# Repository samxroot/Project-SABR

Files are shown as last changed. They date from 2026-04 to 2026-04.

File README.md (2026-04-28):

# SABR - Self-Balancing Robot (Inverted Pendulum)

[](https://youtu.be/h8H8bgWLwpI)

[sabr-demo]: https://img.youtube.com/vi/h8H8bgWLwpI/maxresdefault.jpg

### A LIGIENCE Project

**SABR** is a self-balancing robot built from scratch using control theory, embedded systems, and iterative engineering. This project explores the inverted pendulum problem in a real-world system using sensor fusion and PID control.

## Quick Start

### 1. Hardware

- 3D print parts from `hardware/cad/stl/`
- Order PCB from `hardware/pcb/gerbers/`
- Follow wiring diagram in `docs/wiring.md`

### 2. Firmware

- Open `firmware/sabr.ino`
- Upload to ESP32 using Arduino IDE or PlatformIO

### 3. Run

- Power the robot upright
- Tune PID values if needed (`config.h` or inline constants)

## Overview

**SABR** balances using:

- IMU-based angle measurement (MPU6050)
- Sensor fusion (Kalman / Complementary filter)
- PID control loop (~200Hz)
- Real-time motor correction

## Features

- [x] Custom mechanical design (CAD + 3D printed)
- [x] Custom PCB (KiCad)
- [x] Sensor fusion (Kalman / Complementary filter)
- [x] 200 Hz PID control loop
- [x] Real-time motor correction
- [x] Multiple motor configurations tested

## Project Structure

```
hardware/
  ├── cad/            # STEP + STL files
  ├── pcb/            # Gerbers + schematic
  └── electronics/    # Fritzing

firmware/
  └── sabr.ino

docs/
  ├── build-guide.md
  ├── motor-sizing.md
  └── development.md

media/
```

## Components

| Component | Details |
|---|---|
| **Microcontroller** | ESP32 Dev Module |
| **IMU** | MPU6050 (6-axis accelerometer + gyroscope) |
| **Motors** | NEMA 17 Stepper Motors |
| **Motor Drivers** | TMC2208 |
| **Power** | LiPo Battery + Buck Converter |
| **Frame** | Custom PCB + 3D printed chassis |

Full component list: [`hardware/BOM.md`](hardware/BOM.md)

## How It Works

```
IMU Data → Sensor Fusion → PID Controller → Motor Output → Balance
```

- Control loop runs at ~200Hz
- D-term uses gyroscope data directly for stability
- Kalman filter tuned with high gyro weighting (>95%)

## Documentation

| Resource | Link |
|---|---|
| Build Guide | [`docs/build-guide.md`](docs/build-guide.md) |
| Motor Sizing | [`docs/motor-sizing.md`](docs/motor-sizing.md) |
| Development Process | [`docs/development.md`](docs/development.md) |

### Additional Learning Resources

**Sensor Fusion & Filtering:**
- [Complementary & Kalman Filters Overview](https://youtu.be/7HVPjkWOrLE?si=l8aKTfFblnUTjnXL)
- [Complementary Filter Deep Dive](https://youtu.be/hQUkiC5o0JI?si=4qGIxBiCNVThZBNw)
- [Kalman Filter Implementation](https://youtu.be/RZd6XDx5VXo?si=hTg3l8ioiw1hPVCZ)

**IMU Processing:**
- [Accelerometer Roll & Pitch Explanation](https://mwrona.com/posts/accel-roll-pitch/)

## Visuals

### Circuit Diagram
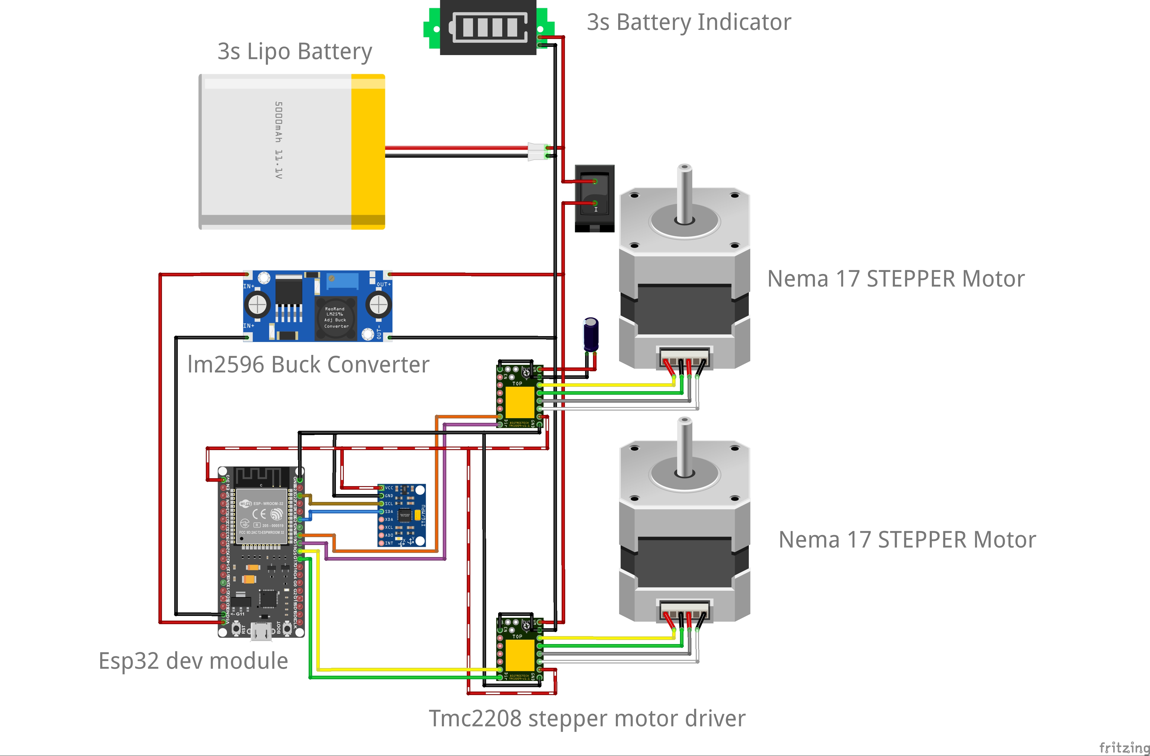
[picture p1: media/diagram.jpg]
Circuit Diagram


### Schematics
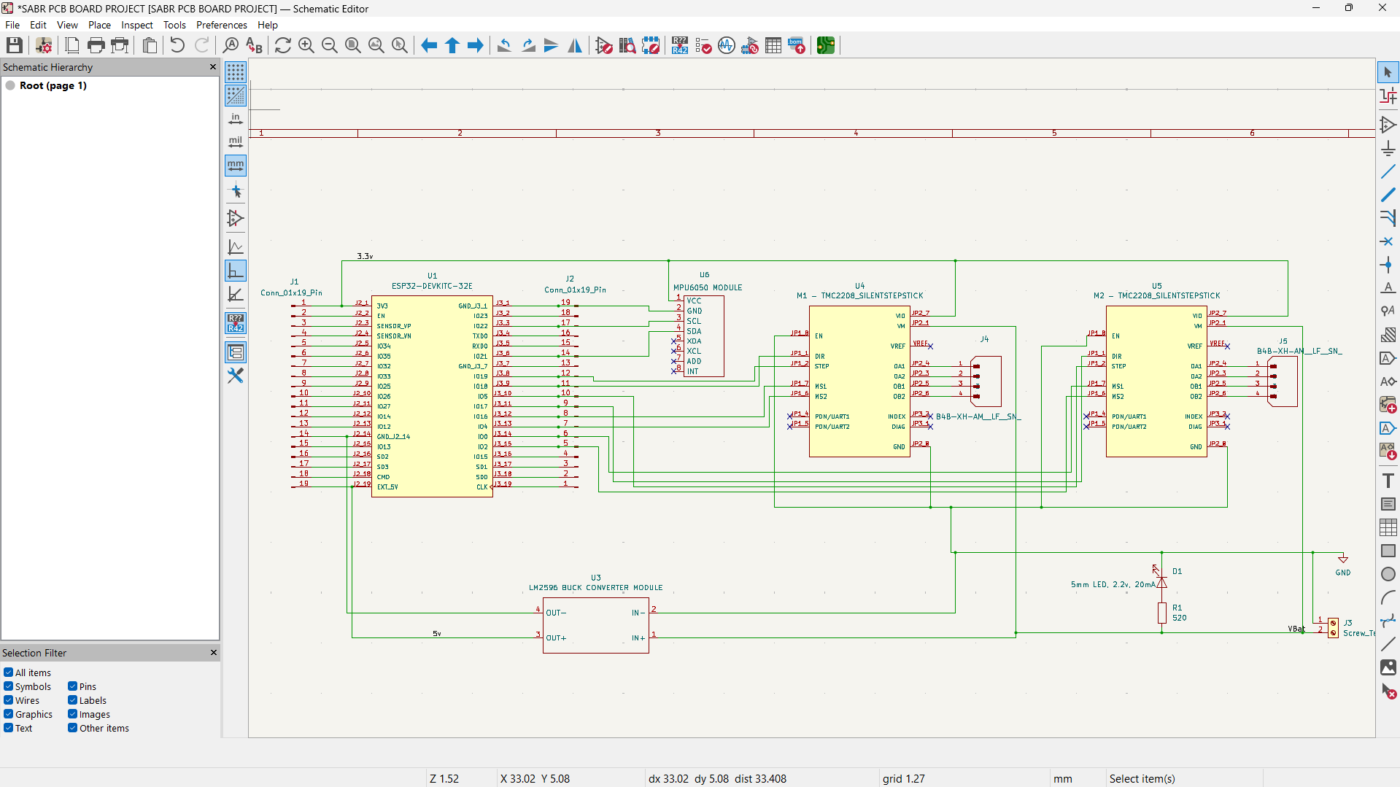
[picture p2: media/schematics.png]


### PCB Layout
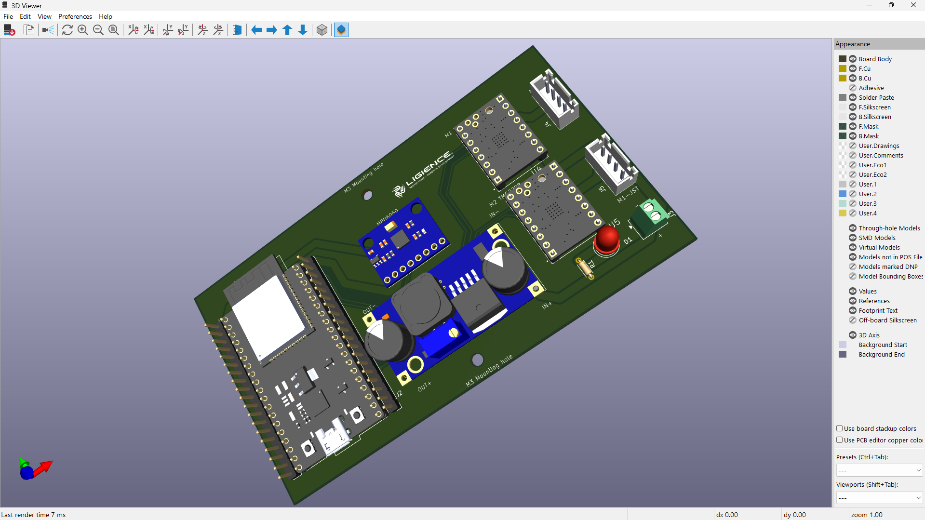
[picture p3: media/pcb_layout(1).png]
PCB Layout

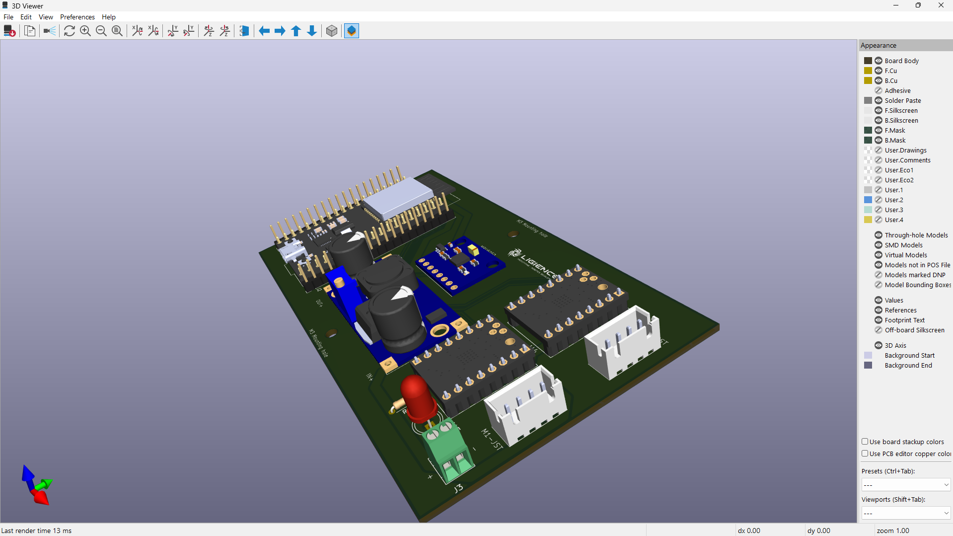
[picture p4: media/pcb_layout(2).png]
PCB Layout


### 3D Model
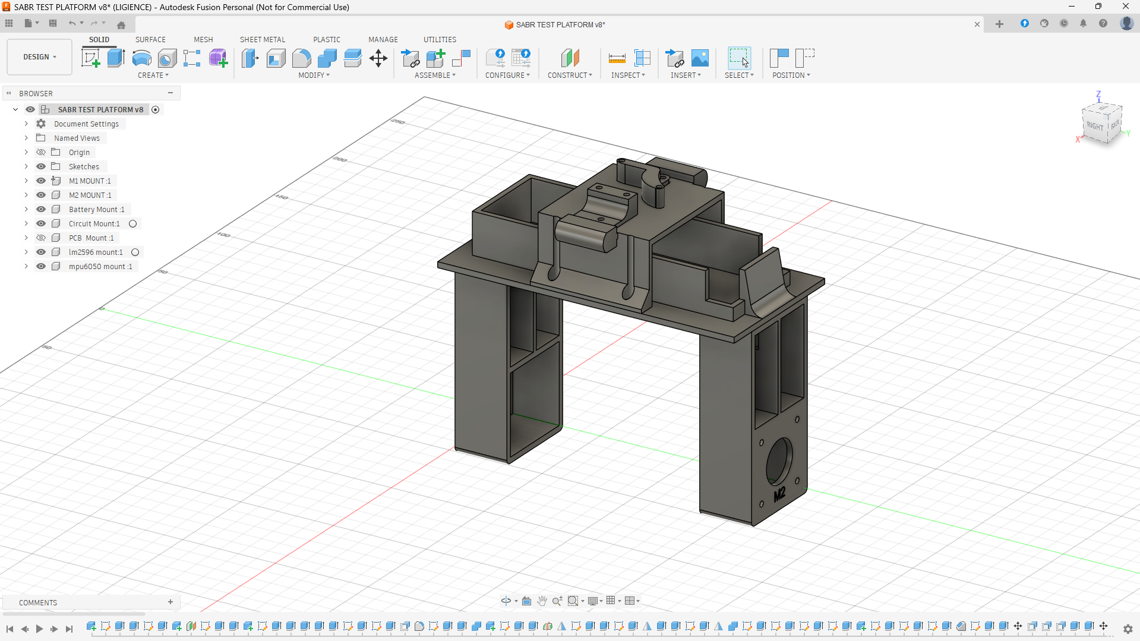
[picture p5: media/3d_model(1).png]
3D Model

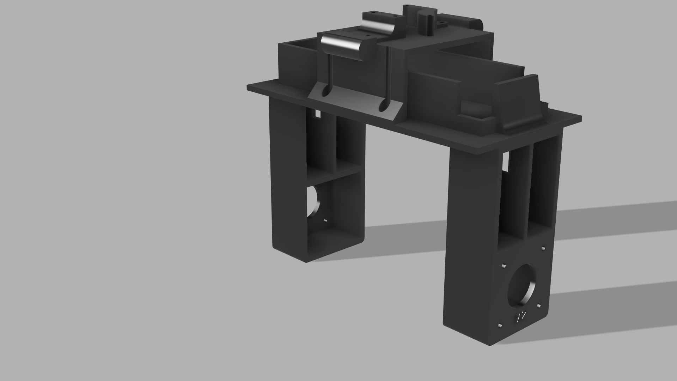
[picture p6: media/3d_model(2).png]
3D Model

<div align="center">
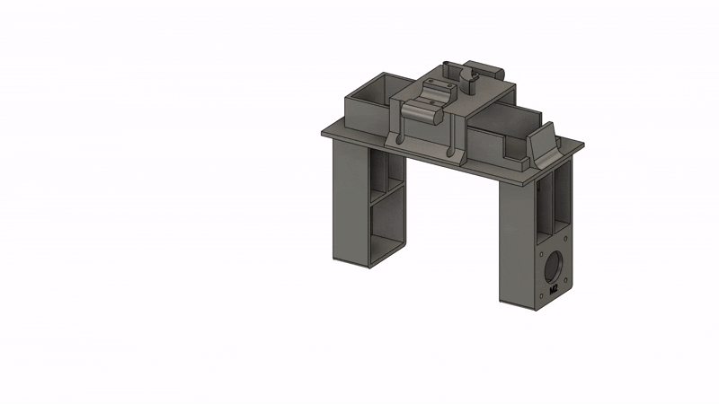
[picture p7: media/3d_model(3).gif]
3D Model Animation
  
</div>

## Known Issues & Future Work

- [ ] Add position/velocity control (reduce drift)
- [ ] Improve wheel grip (silicone tyres)
- [ ] Add power switch to PCB
- [ ] Add wheel encoders for odometry
- [ ] Explore BLDC motors with FOC control

## Credits

- Inspiration: [Aaed Musa's Impulse Robot](https://youtu.be/WIU8gnqQJJM)
- PCB Manufacturing: [PCBWay](https://www.pcbway.com)
- Control Theory References: See `/docs`

*Part of the LIGIENCE robotics series - building real robots from first principles.*

## License

[MIT License](LICENSE)

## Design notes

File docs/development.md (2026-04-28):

# Development Journey

## Phase 1 — Physics & Modelling

* Inverted pendulum system
* Derived equations of motion

## Phase 2 — Prototyping

* ESP32 + MPU6050
* Complementary & Kalman filters tested

## Phase 3 — Stepper V1

* Torque issues, overheating

## Phase 4 — Stepper V2

* Improved but unstable

## Phase 5 — Motor Experiments

* DC motors → dead zone issues
* Servos → too slow

## Phase 6 — Breakthrough

* Root issue: wheel friction
* Successful balancing on carpet
* Kalman tuning improved stability

## Phase 7 — Final Tuning

* PID tuning (Kp → Kd → Ki)
* Gyro-based D term
* Stable balancing achieved

## Key Lessons

* Hardware matters more than tuning
* Friction is critical
* Motor response speed is everything

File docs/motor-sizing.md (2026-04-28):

# Motor Sizing & Torque Calculation
Source: [CTMS - Inverted Pendulum Model](https://ctms.engin.umich.edu/CTMS/?example=InvertedPendulum&section=SystemModeling)

## Formula

`τ = m · g · L · sin(θ)`

## Variables

- **τ** - Torque (N·m)
- **m** - Mass of the robot (kg)
- **g** - Gravitational acceleration (9.81 m/s²)
- **L** - Distance from wheel axle to center of mass (m)
- **θ** - Tilt angle (degrees)

## Guidelines

- Use θ ≥ 30° as the minimum recovery angle.
- Multiply the calculated torque by a 1.5×–2× safety margin.
- Never select motors at the minimum torque specification.

## Key Insights

### Torque vs Inertia

- **Torque ∝ L** - Torque increases with the distance from the pivot.
- **Inertia ∝ L²** - Longer robots require more torque to counterbalance increased inertia.

### Dead Zones

DC motors often have a 0–40% PWM dead zone, where small PID corrections may fail to move the motor.

### Stepper Limitations

- Stepper motors can overheat due to high current draw at standstill.
- This can lead to thermal shutdown under continuous correction.

### Critical Rule

You cannot fix insufficient hardware with PID tuning. Ensure your motor provides enough torque and response speed.

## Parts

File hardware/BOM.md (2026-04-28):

## Components
* ESP32 Dev Module
* MPU6050 IMU
* NEMA 17 Stepper Motors (final version)
* TMC2208 Drivers
* LiPo Battery + Buck Converter
* Custom PCB + 3D printed frame

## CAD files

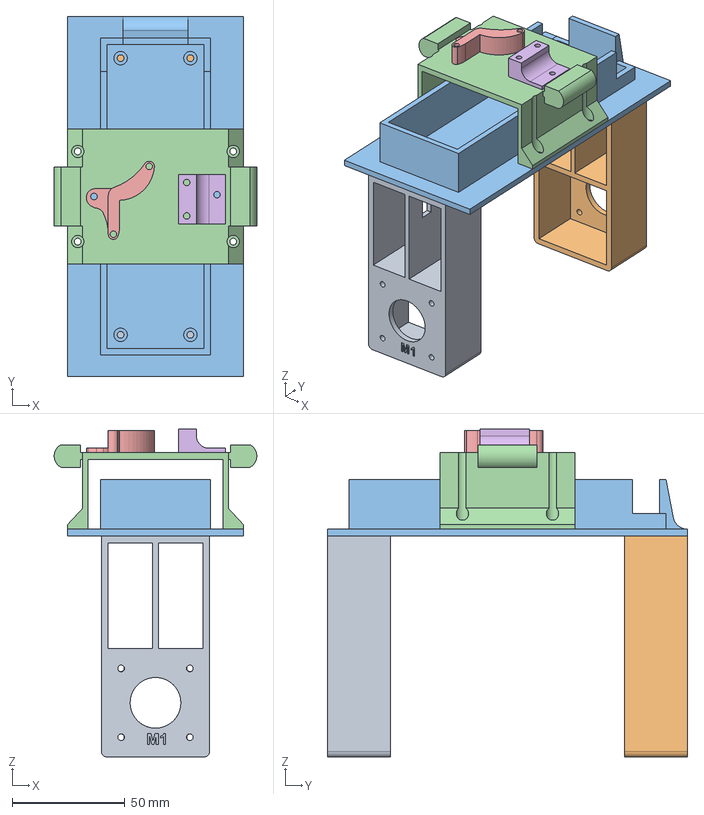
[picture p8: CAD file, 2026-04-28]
hardware/cad/step/test-platform.step
90.0 x 160.0 x 145.6 mm
M1 MOUNT
M2 MOUNT
Battery Mount
Circuit Mount
lm2596 mount
mpu6050 mount

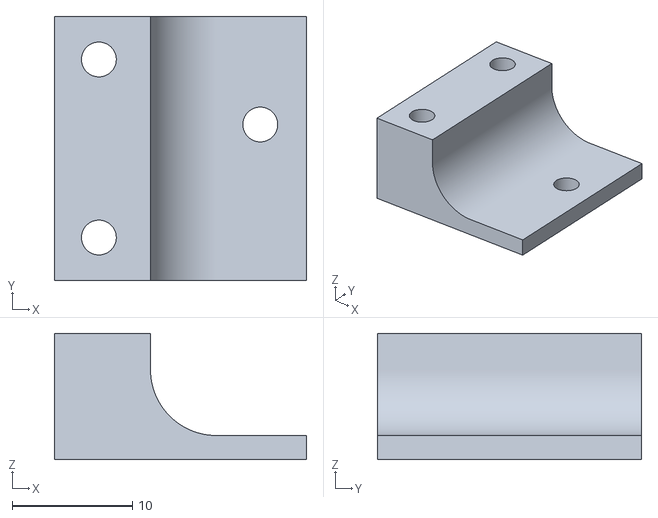
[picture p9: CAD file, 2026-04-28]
hardware/cad/stl/MPU6050 Mount.stl
21.0 x 22.0 x 10.5

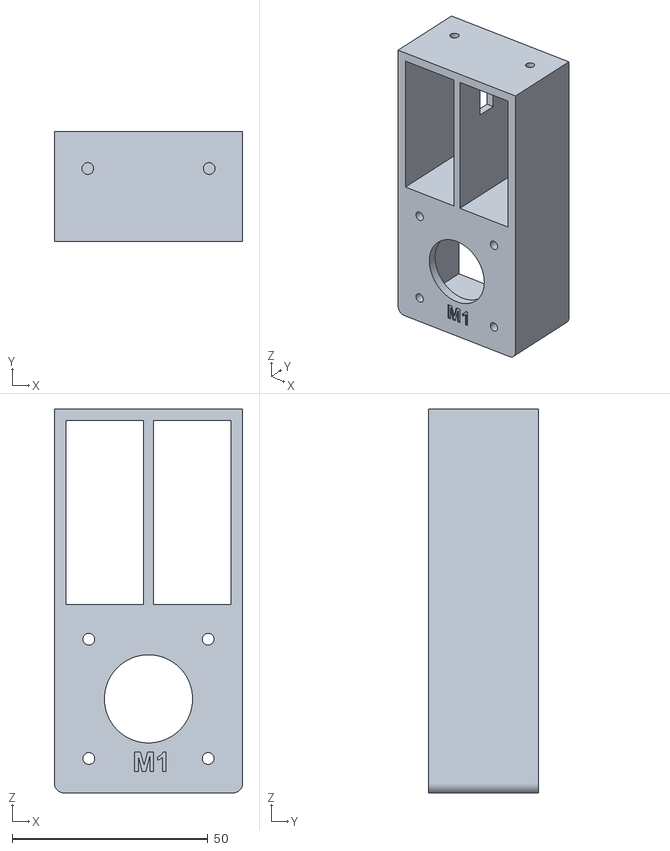
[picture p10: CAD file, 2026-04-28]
hardware/cad/stl/M1 Mount.stl
48.1 x 28.0 x 98.1

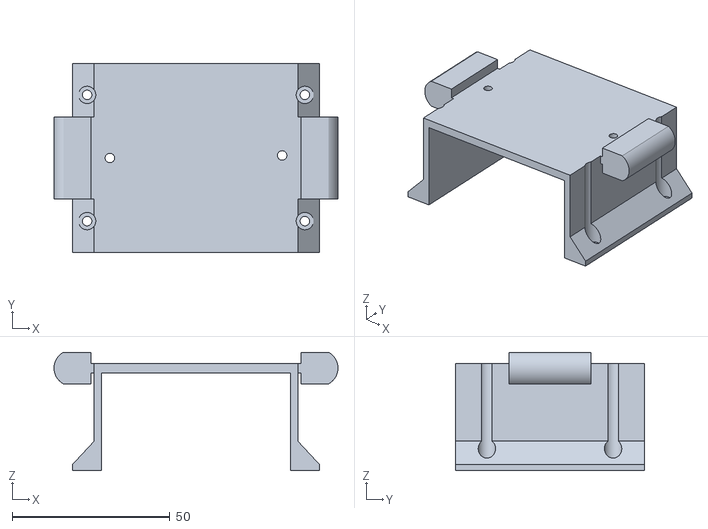
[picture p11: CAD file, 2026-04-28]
hardware/cad/stl/Circuit Mount.stl
90.0 x 60.0 x 37.5

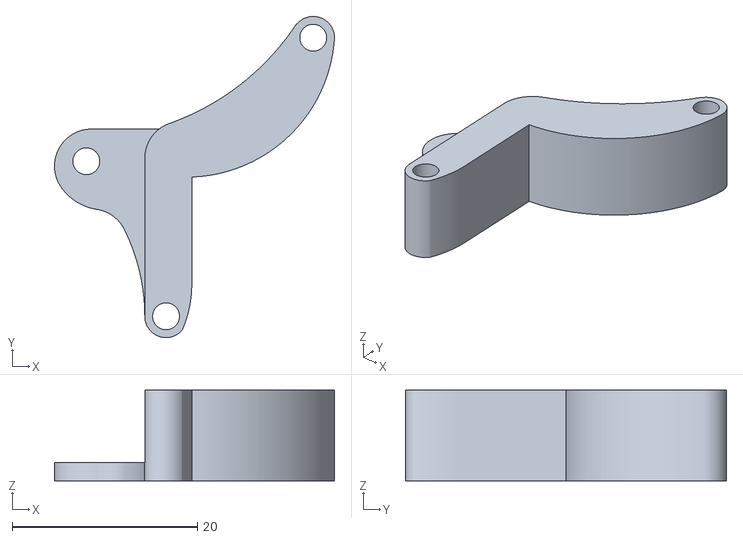
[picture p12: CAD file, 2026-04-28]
hardware/cad/stl/LM2596 Mount.stl
30.3 x 34.7 x 9.80

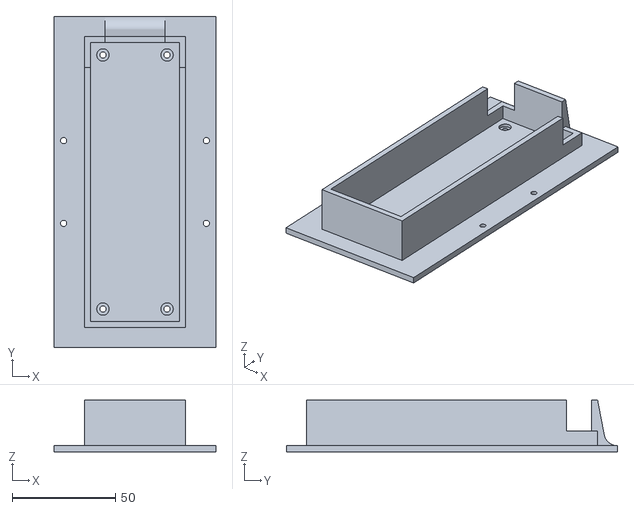
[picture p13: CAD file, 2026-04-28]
hardware/cad/stl/Battery Mount.stl
78.1 x 160.0 x 25.0

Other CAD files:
hardware/cad/stl/M2 Mount.stl

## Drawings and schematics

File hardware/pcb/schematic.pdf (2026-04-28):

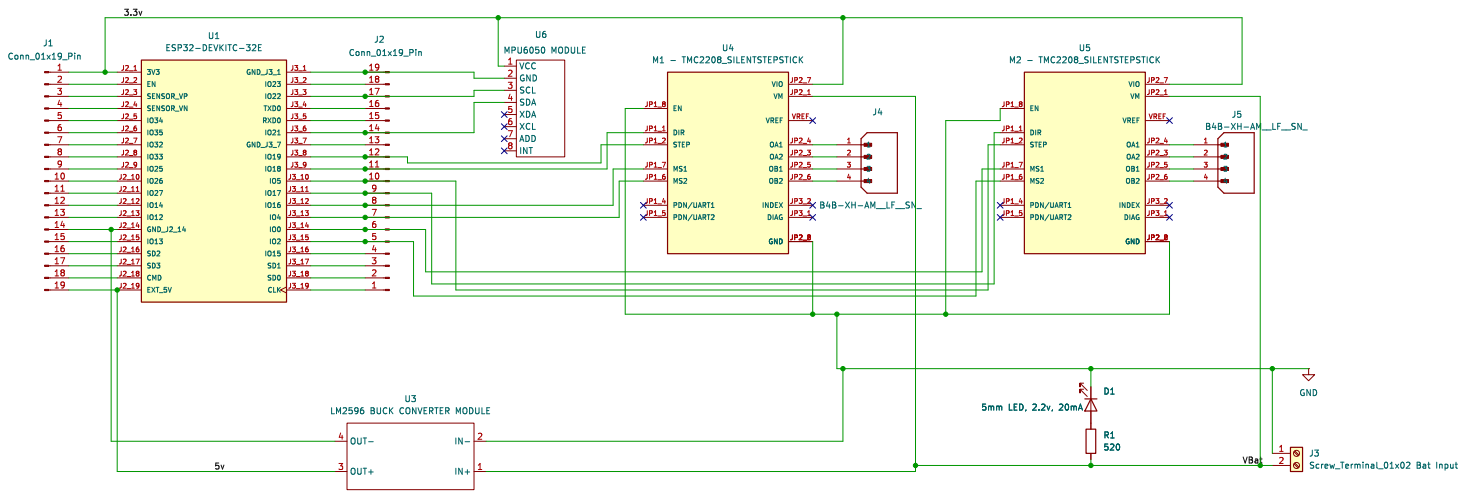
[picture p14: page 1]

Id: 1/1 Title: SABR PCB DESING

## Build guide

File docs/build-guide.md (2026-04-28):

# Build Guide (Overview)
Follow along: [A Self Balancing Robot Journey | Building SABR](https://youtu.be/h8H8bgWLwpI)

## 1. Print Parts

Use STL files in `hardware/cad/stl/`

## 2. Assemble Frame

* Mount motors
* Attach wheels
* Secure electronics

## 3. PCB

* Order from `hardware/pcb/gerbers/`
* Solder components

## 4. Wiring

Follow `docs/wiring.md`

## 5. Upload Firmware

Flash `firmware/sabr.ino` to ESP32

## 6. First Test

* Hold robot upright
* Power on
* Adjust PID if unstable

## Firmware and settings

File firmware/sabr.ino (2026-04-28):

// PLEASE UNDERSTAND I WRITE COMMENTS MY OWN WAY,
// BUT NONETHELESS THE BUILD VIDEO FOR THIS IS ON YOUTUBE @LIGIENCE
// Link: https://youtube.com/@LIGIENCE

#include <Wire.h>
#include <math.h> // Required for sqrt, atan2f, fabsf

// -------------------- IMU VARIABLES --------------------

float Gyro_Roll, Gyro_Pitch, Gyro_Yaw;
//       p         q          r

float AccX, AccY, AccZ;
//      x     y     z

float Acc_Roll, Acc_Pitch;

// Sampling rate
// 0.004s approx 200-250Hz depending on execution timing
float sampling_rate = 0.004f;
unsigned long sampling_rate_timer = 4000; // microseconds

unsigned long SR_current_timer;
unsigned long SR_last_timer;


// --------------------- MPU6050 ACCELEROMETER AND GYRO READINGS ---------------------

void Accel_gyro_signals(void) {

  Wire.beginTransmission(0x68);
  Wire.write(0x1A);
  Wire.write(0x05);
  Wire.endTransmission();

  Wire.beginTransmission(0x68);
  Wire.write(0x1C);
  Wire.write(0x10);
  Wire.endTransmission();

  Wire.beginTransmission(0x68);
  Wire.write(0x3B);
  Wire.endTransmission();

  Wire.requestFrom(0x68, 6);

  int16_t AccXLSB = Wire.read() << 8 | Wire.read();
  int16_t AccYLSB = Wire.read() << 8 | Wire.read();
  int16_t AccZLSB = Wire.read() << 8 | Wire.read();


  Wire.beginTransmission(0x68);
  Wire.write(0x1B);
  Wire.write(0x08);
  Wire.endTransmission();

  Wire.beginTransmission(0x68);
  Wire.write(0x43);
  Wire.endTransmission();

  Wire.requestFrom(0x68, 6);

  int16_t GyroX = Wire.read() << 8 | Wire.read();
  int16_t GyroY = Wire.read() << 8 | Wire.read();
  int16_t GyroZ = Wire.read() << 8 | Wire.read();


  // Gyro -> deg/s (with calibration offsets)
  Gyro_Roll  = (float)GyroX / 65.5 + 1.40;
  Gyro_Pitch = (float)GyroY / 65.5 - 4.13;
  Gyro_Yaw   = (float)GyroZ / 65.5 + 0.78;


  // Accelerometer -> g (with offsets)
  AccX = (float)AccXLSB / 4096.0f - 0.02f;
  AccY = (float)AccYLSB / 4096.0f - 0.05f;
  AccZ = (float)AccZLSB / 4096.0f - 0.029f;


  // Always normalize (but avoid division by zero)
  float acc_magnitude = sqrt(AccX * AccX + AccY * AccY + AccZ * AccZ);

  if (acc_magnitude > 0.1f) {
    AccX /= acc_magnitude;
    AccY /= acc_magnitude;
    AccZ /= acc_magnitude;
  }


  // Convert to angles
  Acc_Pitch = atan2f(-AccX, sqrt(AccY * AccY + AccZ * AccZ)) * RAD_TO_DEG;
  Acc_Roll  = atan2f(AccY, AccZ) * RAD_TO_DEG;
}


// -------------------- KALMAN FILTER VARIABLES --------------------

float KalmanAngleRoll = 0.0f;
float KalmanUncertaintyRoll = 2.0f * 2.0f;

float KalmanAnglePitch = 0.0f;
float KalmanUncertaintyPitch = 2.0f * 2.0f;


// Noise tuning (this is where the magic pain lives)
const float Q_angle = 0.003f; // gyro trust
const float R_angle = 0.05f;  // accel trust


// -------------------- KALMAN FILTER --------------------

void Kalman_1d(float &KalmanState,
               float &KalmanUncertainty,
               float KalmanInput,
               float KalmanMeasurement) {

  // Prediction (gyro)
  KalmanState += KalmanInput * sampling_rate;
  KalmanUncertainty += Q_angle * sampling_rate;

  // Kalman gain
  float KalmanGain = KalmanUncertainty /
                     (KalmanUncertainty + R_angle);

  // Update
  KalmanState += KalmanGain *
                (KalmanMeasurement - KalmanState);

  KalmanUncertainty =
      (1.0f - KalmanGain) * KalmanUncertainty;
}


// -------------------- CONTROL MODE --------------------

uint8_t control_mode = 1;  // 0 = angle only, 1 = angle + position


// -------------------- MOTOR POSITION TRACKING --------------------

volatile int32_t motor_left_steps = 0;
volatile int32_t motor_right_steps = 0;

int32_t position_avg = 0;


// -------------------- ANGLE PID --------------------

float angle_setpoint = 3.0f; // yes this moves dynamically later
float angle_error = 0.0f;

float KP_angle = 280.0f;
float Ki_angle = 20.0f;
float Kd_angle = 2.5f;

float Integral_angle = 0.0f;
float Integral_angle_max = 500.0f;

float PID_angle_output = 0.0f;


// -------------------- POSITION PID --------------------

float position_setpoint = 0.0f;
float position_error = 0.0f;

float KP_pos = 1.5f;
float Ki_pos = 0.0f;
float Kd_pos = 0.0f;

float Integral_pos = 0.0f;
float Integral_pos_max = 35.0f;

float position_prev = 0.0f;

float PID_pos_output = 0.0f;

#define PID_POS_MAX 35.0f

float POSITION_DEADZONE = 0.5f;


// -------------------- ANGLE PID FUNCTION --------------------

void angle_PID() {

  angle_error = angle_setpoint - KalmanAnglePitch;

  float P = KP_angle * angle_error;

  // anti-windup (because reality is annoying)
  if (fabsf(angle_error) < 8.0f &&
      fabsf(PID_angle_output) < 500.0f) {

    Integral_angle += angle_error * sampling_rate;
    Integral_angle =
      constrain(Integral_angle,
                -Integral_angle_max,
                 Integral_angle_max);
  } else {
    Integral_angle = 0.0f;
  }

  float I = Ki_angle * Integral_angle;

  // derivative = gyro (because noise is pain)
  float D = -Kd_angle * Gyro_Pitch;

  PID_angle_output = P + I + D;
}


// -------------------- POSITION PID FUNCTION --------------------

void position_PID() {

  position_error =
    (position_setpoint - position_avg) / 1000.0f;

  float P = KP_pos * position_error;

  Integral_pos += position_error * sampling_rate;
  Integral_pos =
    constrain(Integral_pos,
              -Integral_pos_max,
               Integral_pos_max);

  if (fabsf(position_error) > 2.0f) {
    Integral_pos = 0.0f;
  }

  float I = Ki_pos * Integral_pos;

  float pos_rate =
    (position_avg - position_prev) / sampling_rate;

  position_prev = position_avg;

  float D = -Kd_pos * (pos_rate / 1000.0f);

  PID_pos_output = P + I + D;

  PID_pos_output =
    constrain(PID_pos_output,
              -PID_POS_MAX,
               PID_POS_MAX);
}


// -------------------- STEPPER MOTOR CONFIG --------------------

float p;
int steps_per_rev = 1600;


// -------------------- PINS --------------------

const int DIR = 18;
const int STEP = 19;
const int MS1_M1 = 16;
const int MS2_M1 = 4;

const int DIR2 = 17;
const int STEP2 = 5;
const int MS1_M2 = 0;
const int MS2_M2 = 2;


// -------------------- TIMERS --------------------

unsigned long stepper_motor_us_pulse;
unsigned long M_Current_timer;
unsigned long M_Last_timer;


// -------------------- MICROSTEPPING --------------------

uint8_t microStep = 8;


// -------------------- MICROSTEP FUNCTION --------------------

void setMicroStep(uint8_t uStep) {

  switch (uStep) {

    case 2:
      digitalWrite(MS1_M1, LOW);
      digitalWrite(MS2_M1, HIGH);
      digitalWrite(MS1_M2, LOW);
      digitalWrite(MS2_M2, HIGH);
      steps_per_rev = 400;
      break;

    case 4:
      digitalWrite(MS1_M1, HIGH);
      digitalWrite(MS2_M1, LOW);
      digitalWrite(MS1_M2, HIGH);
      digitalWrite(MS2_M2, LOW);
      steps_per_rev = 800;
      break;

    case 8:
      digitalWrite(MS1_M1, LOW);
      digitalWrite(MS2_M1, LOW);
      digitalWrite(MS1_M2, LOW);
      digitalWrite(MS2_M2, LOW);
      steps_per_rev = 1600;
      break;

    case 16:
      digitalWrite(MS1_M1, HIGH);
      digitalWrite(MS2_M1, HIGH);
      digitalWrite(MS1_M2, HIGH);
      digitalWrite(MS2_M2, HIGH);
      steps_per_rev = 3200;
      break;

    default:
      steps_per_rev = 1600;
      uStep = 8;
      break;
  }

  microStep = uStep;
}


// -------------------- TASK HANDLES --------------------

TaskHandle_t Task1;
TaskHandle_t Task2;


// -------------------- SETUP --------------------

void setup() {

  Serial.begin(115200);

  Wire.setClock(400000);
  Wire.begin();

  delay(250);

  Wire.beginTransmission(0x68);
  Wire.write(0x6B);
  Wire.write(0x00);
  Wire.endTransmission();


  pinMode(STEP, OUTPUT);
  pinMode(DIR, OUTPUT);
  pinMode(MS1_M1, OUTPUT);
  pinMode(MS2_M1, OUTPUT);

  pinMode(STEP2, OUTPUT);
  pinMode(DIR2, OUTPUT);
  pinMode(MS1_M2, OUTPUT);
  pinMode(MS2_M2, OUTPUT);


  setMicroStep(8);
  control_mode = 1;

  delay(250);

  M_Last_timer = micros();
  SR_last_timer = micros();


  // Task 1 (IMU + control)
  xTaskCreatePinnedToCore(
    Task1code,
    "Task1",
    10000,
    NULL,
    1,
    &Task1,
    0
  );

  delay(500);


  // Task 2 (motor stepping)
  xTaskCreatePinnedToCore(
    Task2code,
    "Task2",
    10000,
    NULL,
    1,
    &Task2,
    1
  );

  delay(500);
}


// -------------------- TASK 1 --------------------

void Task1code(void *pvParameters) {

  Serial.println("Task1 running on core " +
                 String(xPortGetCoreID()));

  for (;;) {

    SR_current_timer = micros();

    if (SR_current_timer - SR_last_timer >=
        sampling_rate_timer) {

      Accel_gyro_signals();

      Kalman_1d(KalmanAnglePitch,
                KalmanUncertaintyPitch,
                Gyro_Pitch,
                Acc_Pitch);

      position_avg =
        (motor_left_steps +
         motor_right_steps) / 2;


      if (control_mode == 0) {

        angle_setpoint = 3.0f;
        angle_PID();

      } else {

        position_PID();
        angle_setpoint = PID_pos_output + 2.0f;
        angle_PID();
      }


      p = fabsf(PID_angle_output);
      p = constrain(p, 0.001f, 40000.0f);


      setMicroStep(8);


      if (PID_angle_output > 0) {

        digitalWrite(DIR, LOW);
        digitalWrite(DIR2, HIGH);

        stepper_motor_us_pulse =
          (unsigned long)(1000000.0f / p);

      } else {

        digitalWrite(DIR, HIGH);
        digitalWrite(DIR2, LOW);

        stepper_motor_us_pulse =
          (unsigned long)(1000000.0f / p);
      }


      if (fabsf(angle_error) < 0.3f) {
        stepper_motor_us_pulse = 100000UL;
      }

      if (fabsf(angle_error) > 45.0f) {
        stepper_motor_us_pulse = 100000UL;
      }


      SR_last_timer = SR_current_timer;
    }
  }
}


// -------------------- TASK 2 --------------------

void Task2code(void *pvParameters) {

  Serial.println("Task2 running on core " +
                 String(xPortGetCoreID()));

  for (;;) {

    M_Current_timer = micros();

    if (M_Current_timer - M_Last_timer >=
        stepper_motor_us_pulse) {

      digitalWrite(STEP, HIGH);
      digitalWrite(STEP2, HIGH);

      delayMicroseconds(1);

      digitalWrite(STEP, LOW);
      digitalWrite(STEP2, LOW);


      if (digitalRead(DIR) == LOW) {
        motor_left_steps++;
      } else {
        motor_left_steps--;
      }

      if (digitalRead(DIR2) == HIGH) {
        motor_right_steps++;
      } else {
        motor_right_steps--;
      }

      M_Last_timer = M_Current_timer;
    }
  }
}


// -------------------- LOOP --------------------

void loop() {
  // intentionally empty (RTOS takes over)
}
